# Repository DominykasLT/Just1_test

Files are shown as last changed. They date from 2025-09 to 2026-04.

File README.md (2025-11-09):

# Just1 - An Open-Source Autonomous Mecanum Wheel Robot

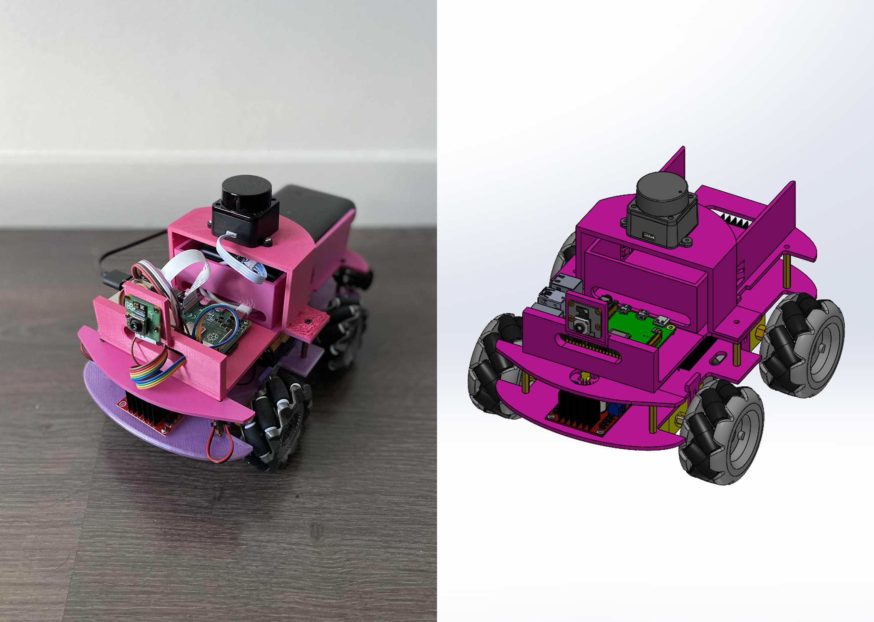
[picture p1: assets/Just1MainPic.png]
Just1MainPic


# Watch the Demo!
<a href="https://www.youtube.com/watch?v=m_tZ3eg-KsA" target="_blank">
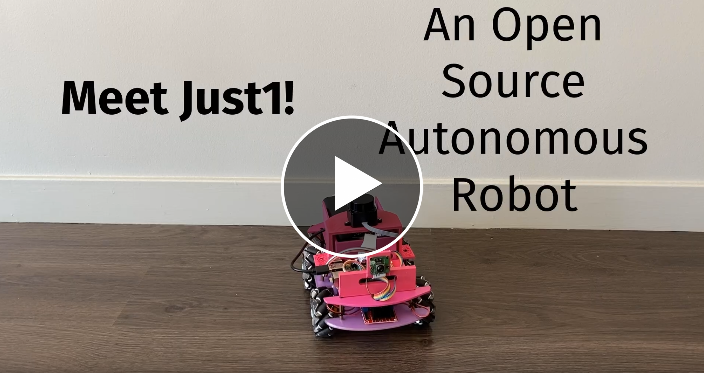
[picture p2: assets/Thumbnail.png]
Watch the demo
  
</a>

<br>
<br> 

I have written 2 blog articles about Just1:   
- [How I built a small autonomous robot](https://nrdrgz.github.io/2025/10/21/building-just1-autonomous-robot/)
- [How I used Foxglove](https://nrdrgz.github.io/2025/10/22/foxglove-studio-robotics-visualization/)

Just1 is an open-source robotics platform designed for learning and experimentation.  
It can navigate manually or autonomously, follow a path, avoid obstacles.  

Its hardware stack is composed of:

- Raspberry Pi 4
- Mecanum wheels
- TT motors
- 2D Lidar
- Rasberry Pi Camera
- IMU

Its software stack is composed of:

- ROS2 Jazzy for middleware
- Madgwick filter for IMU
- RTAB-Map for SLAM and odometry
- Nav2 for navigation
- Foxglove for sensor feedback and overall monitoring

Complete build cost: just $250.

Just1 operates in two modes: autonomous navigation with Lidar-based obstacle avoidance, or manual control via gamepad.  
Originally designed for camera-only VSLAM navigation, Just1 now uses Lidar for more reliable obstacle detection and easier software development. Future versions will integrate both camera and Lidar for enhanced autonomous navigation.  
One limit of the current architecture is that obstacles below 20cm are not detected due to the Lidar's position.

Here are some performance highlights (tested on a flat indoor surface):
- Maximum forward speed: 0.6 m/s
- Maximum sideways (lateral) speed: 0.5 m/s
- Maximum rotational speed: 3.5 rad/s (204°/s)
- Operates reliably in complete darkness thanks to its Lidar

## Project Goals

Just1 was created with these objectives in mind:
- Create an affordable, well-documented platform for robotics learning and experimentation
- Develop practical robotics skills, both in hardware and software
- Share knowledge and encourage others to build their own robots

## Workspace Organization

### Hardware
Located in `/Bot/Hardware`:
- Bill of Materials (BoM)
- CAD design files
- Wiring diagrams

### Software
Located in `/Bot/Software`:
- ROS2 packages
- Installation guides
- Manual and autonomous control documentation

## Current Features

- Complete hardware design with BoM and CAD files
- Comprehensive software documentation for Raspberry Pi setup and ROS2 installation
- Manual control using Nintendo controller
- Autonomous navigation using SLAM and Nav2
- Sensor feedback accessible via Foxglove

## Long-term Goals and Potential Improvements

- Add a Docker image for easier and faster deployment
- Replace AA batteries with voltage booster for simplified power management
- Add a bunch of unit tests 
- Add support for carrying the SO-101 robotic arm
- Add wheel encoders to improve ICP odometry
- Add an explorer node to automatically explorer and discover the frontiers of the map
- Use camera in combination with the Lidar for autonomous navigation and obstacle avoidance
- Create a simulation environment in NVIDIA Isaac Sim with Just1 replica for training navigation algorithms before hardware deployment
- Integrate memory/latency profilers to optimize processes and detect memory leaks
- Perform navigation through end-to-end neural network architecture instead of VSLAM

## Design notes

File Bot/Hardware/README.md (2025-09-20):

# Just1 Hardware

This folder contains hardware documentation and files for the Just1 robot.

## Bill of Materials
See `Bill_of_material.md` for complete parts list and pricing. Total cost is around $250.

**Key Components:**
- Raspberry Pi 4 (8GB) - Control unit
- 4x Mecanum wheels with TT motors - Omnidirectional movement
- 2x L298N motor drivers - Motor control
- LD19 Lidar - 2D scanning for navigation
- MPU6050 IMU - Orientation sensing
- Camera Module 3 - Optional vision sensor
- Power bank (5V 3A) - Pi power supply
- 6x AA battery holder - Motor power (9V)
The 6x AA battery holder can eventually be replaced with a rechargeable battery pack or by connecting the motors directly to the power bank using an appropriate power adapter.

**Additional parts:** Jumper wires, screws, hex pylons, on/off switch, and basic tools.

## 3D Models
- **Assembly**: `CAD/Just1Assembly.STEP` - Complete robot model
- **Print Files**: `CAD/ToPrint/` - STL files for 3D printing the different parts.

## Wiring Schematics
- `WiringMotorDrivers.png` - Motor driver connections
- `WiringPower.png` - Power distribution diagram

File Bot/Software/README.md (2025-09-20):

# Just1 Software

Instructions to set up the robot from a raw SD card to autonomous navigation.

## Installation

1. **Install Ubuntu Server 24.04 on your Pi**
   - See `How_to/How_to_Install_Ubuntu_on_Pi.md`
   - Connect via SSH to your Pi, then continue

2. **Install ROS2 on your Pi**
   - See `How_to/How_to_Install_ROS2_on_Pi.md`
   - Note: Do not use a virtual environment (causes issues with Camera and ROS2)

3. **Install git and clone this repository on your Pi**
```bash
sudo apt install git -y
git clone https://github.com/NRdrgz/Just1.git
cd Just1/Bot/Software
```

4. **Install Dependencies**
```bash
sudo apt install python3-pip python3-gpiozero python3-pygame libcap-dev ninja-build libyaml-dev python3-yaml python3-ply python3-jinja2 meson ros-jazzy-foxglove-bridge ros-jazzy-foxglove-msgs python3-smbus i2c-tools ros-jazzy-rtabmap-ros ros-jazzy-imu-filter-madgwick ros-jazzy-navigation2 ros-jazzy-nav2-bringup
sudo pip install --break-system-packages -r requirements.txt
```

5. **Build libcamera from source**
   - libcamera is not available on Ubuntu Server 24.04 (as of July 2025)
```bash
cd ~
git clone https://git.libcamera.org/libcamera/libcamera.git
cd libcamera
meson setup build
sudo ninja -C build install
```
   Add directory to Python search path:
```bash
echo 'export PYTHONPATH=/usr/local/lib/python3/dist-packages:$PYTHONPATH' >> ~/.bashrc
source ~/.bashrc
```

And libcamera-apps
```bash
cd ~
git clone https://github.com/raspberrypi/libcamera-apps.git
cd libcamera-apps
meson setup build
sudo ninja -C build install
```
   Add directory to Python search path:
```bash
echo 'export PYTHONPATH=/usr/local/lib/aarch64-linux-gnu/dist-packages:$PYTHONPATH' >> ~/.bashrc
source ~/.bashrc
echo "/usr/local/lib/aarch64-linux-gnu" | sudo tee /etc/ld.so.conf.d/libcamera.conf
sudo ldconfig
```

6. **Connect Nintendo Pro Controller (optional)**
   - See `How_to/How_to_Connect_Nintendo_Pro_Controller.md`

7. **Build ROS2 packages**
```bash
cd ~/Just1/Bot/Software
colcon build --symlink-install
```

When working on developing the robot, to build a single package you can do <br>
```bash
colcon build --packages-select <package_name> --symlink-install
```

8. **Source workspace**
```bash
source install/setup.bash
```

## Manual Control

At this point, you can control the robot manually.  
To start the manual control system:

```bash
ros2 launch just1_bringup just1.launch.py mode:=manual
```

If you have connected your controller earlier, you should be able to control the robot manually.

## Autonomous Control

Start autonomous navigation:

```bash
ros2 launch just1_bringup just1.launch.py mode:=autonomous
```

You'll need to use Foxglove to visualize the map and provide a goal to the robot.

## Using Foxglove

The `foxglove_bridge_node` used in `just1_bringup` selects the relevant topics to whitelist for Foxglove.

There are many tutorials available online on how to use Foxglove. It is a powerful tool that allows you to visualize logs, send messages on topics, use ROS2 services, and more.  
We'll focus here on the minimum setup needed to have camera feedback, a map of the surroundings, and the ability to give goals to the robot.

### Setup

1. **Download Foxglove** from https://foxglove.dev/
2. **Open a new connection** > WebSocket connection > Input `ws://raspberrypi:8765` (if you followed `Reads/How_to_Install_Ubuntu_on_Pi.md` and set the hostname as `raspberrypi.local`)
3. **Add panels** to visualize your data

### Required Panels

#### Image Panel
- Add an **Image Panel**
- In the panel settings, select the `/camera/video_h264` topic

#### 3D Map Panel
- Add a **3D Map Panel**
- In the panel settings, configure:
  - **Frame** > Display Frame > `map`
  - **Transform** > Hide all except `base_link` or `odom`
  - **Topics** > Visualize all except `/camera/video_h264`
  - **Publish** > 2D pose topic should be `/goal_pose`

### Navigation
- In the top right corner of the map, right-click on the icon below the ruler > **Publish 2D pose**
- Click on the map to set a goal
- The robot should navigate autonomously to the point while avoiding obstacles!

## Performance Notes

Here is a screenshot of `htop` running while the robot is navigating autonomously:

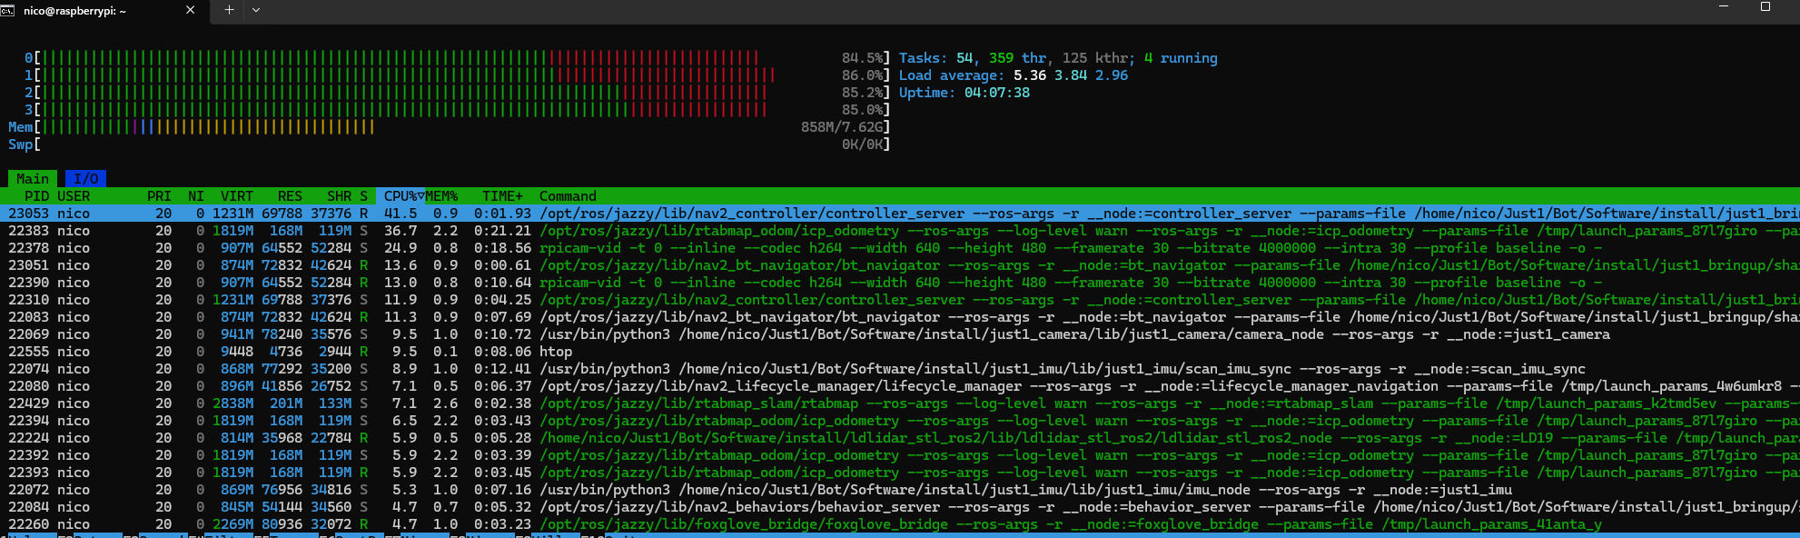
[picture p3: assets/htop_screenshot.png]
htop_screenshot


We can see that CPU usage is near 100%, with Nav2 and RTAB-Map at the top.  
The camera node consumes a significant amount of CPU resources. Moving from JPEG to H.264 encoding definitely improved performance, but it can probably be optimized further by implementing it in C++.
The camera node can eventually be deactivated as it is not strictly required for navigation.

```
 ______  __  __  ______  __  __  __  __      __    __  _____   __  __     
/\__  _\/\ \/\ \/\  _  \/\ \/\ \/\ \/\ \    /\ \  /\ \/\  __`\/\ \/\ \    
\/_/\ \/\ \ \_\ \ \ \L\ \ \ `\\ \ \ \/'/'   \ `\`\\/'/\ \ \/\ \ \ \ \ \   
   \ \ \ \ \  _  \ \  __ \ \ , ` \ \ , <     `\ `\ /'  \ \ \ \ \ \ \ \ \  
    \ \ \ \ \ \ \ \ \ \/\ \ \ \`\ \ \ \\`\     `\ \ \   \ \ \_\ \ \ \_\ \ 
     \ \_\ \ \_\ \_\ \_\ \_\ \_\ \_\ \_\ \_\     \ \_\   \ \_____\ \_____\
      \/_/  \/_/\/_/\/_/\/_/\/_/\/_/\/_/\/_/      \/_/    \/_____/\/_____/     
```

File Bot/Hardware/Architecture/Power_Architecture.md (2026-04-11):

# Power Architecture

## Overview

Just1 uses a single 4S Graphene LiPo drone battery (14.8V nominal, 16.8V max, 1300mAh, 75C) as the sole power source for the entire robot. A single battery eliminates the need for a separate Pi power bank and a motor pack. The LiPo is extremely lightweight, heavily improving the robot's agility and TT motor performance. A BX100 buzzer MUST be plugged into the balance port during operation for low-voltage warning.

## Power Distribution Diagram

```
┌─────────────────────────────────────────────────────────────┐
│  4S Graphene LiPo Battery (14.8V nominal, 16.8V max)       │
│  Requires external BX100 buzzer for low-voltage alarm!      │
└──────────────────┬──────────────────────────────────────────┘
                   │ XT60 (red + / black −) → master switch (see Step 1) → XT60 out → 1→2 splitter → loads
                   │
      ┌────────────┴────────────┐
      │                         │
      ▼                         ▼
┌───────────────┐     ┌──────────────────────────────────┐
│ DC-DC Buck    │     │  DC-DC Buck Converter            │
│ Converter     │     │  Input: up to 16.8V              │
│ (XL4016)      │     │  Output: 5V / 8A (40W)           │
│ Out: 6.0V/8A  │     │  (XL4016)                        │
└──────┬────────┘     └─────────────┬────────────────────┘
       │                            │ BuckVout (5V rail)
       │               ┌────────────┴──────────────────────────────┐
       ▼               │                                           │
┌───────────────┐      ▼                    ▼                      │
│  2× TB6612FNG │ ┌──────────────┐   ┌─────────────────┐           │
│  Motor Driver │ │ RelayCoil+   │   │ Esp32VIN        │           │
│               │ │ Pi5V path    │   │ (always on 5V)  │           │
│  VM: 6.0V     │ │ (switched)   │   └────────┬────────┘           │
│  (safe limits)│ └──────┬───────┘            │                    │
│               │        │    ESP32 GPIO      │                    │
│  4× Encoder   │        │    closes relay    │                    │
│  TT Motors    │        ▼                    │                    │
└───────────────┘ ┌──────────────┐◄───────────┘                    │
                  │ Pi5V_USB-C   │                                 │
                  │ via relay NO │                                 │
                  └──────────────┘                                 │
```

**5V topology:** **ESP32 VIN** and **relay module VCC** tie directly to **buck VOUT+**. Only the **Raspberry Pi 5V** path runs **through the relay contacts** (Pi off, ESP32 still powered). “Upstream of the relay” means **parallel to the Pi feed**, not “before the battery master switch.”

### How the Battery Connects to the System — Physical Wiring Guide

Your battery has two wires: **+ (red)** and **− (black)**. Here is exactly where each wire goes, step by step.

#### Step 1: Battery → XT60 → master switch → XT60 (your harness)

An **XT60** is always **two conductors**: **red = battery +**, **black = battery −** (same pin names on male and female).

Many RC-style harnesses use a **DPST** toggle: **both red and black** run through the switch. **OFF** disconnects the whole pack; **ON** connects both. That matches a battery XT60 on one side of the switch and a second XT60 on the load side — both polarities are switched together.

(Some builds switch **only** the red wire and leave black always tied to a ground bus. Your photos use **both** switched; that is fine and is often safer for storage.)

```
Battery ──XT60──► [ DPST: RED + BLACK both through switch ] ──XT60──► rest of robot
```

#### Step 2: After the switch — 1→2 Splitter → 5V Buck + 6V Buck

Plug the **load-side XT60** of the switch into a **1-to-2 parallel XT60 splitter** (or cut/splice thick wires directly). The two output pairs route the raw up to 16.8V battery voltage to your two buck converters:

| Branch | Red → | Black → |
| --- | --- | --- |
| 1 | Logic Buck (XL4016) **VIN+** | Logic Buck **VIN−** |
| 2 | Motor Buck (XL4016) **VIN+** | Motor Buck **VIN−** |

*Note: The Motor Buck's output (set to exactly 6V) then splices to feed the `VM` pins of both TB6612FNG drivers so they receive a safe 6V limit. Do not connect the battery directly to the TB6612FNG `VM` pins or they will explode (15V limit).*

**Yes — every branch needs both red and black.** DC only flows in a loop; **VM/VIN+ without GND/VIN−** (or the reverse) does nothing useful and can damage something if signals are connected without a common return.

The three blacks from the splitter are **electrically the same node** (battery negative after the switch). They still need to meet the **rest** of the system ground (ESP32, Pi, PCA9685, buck **VOUT−**, etc.) at one **common ground** so logic signals share a reference — use a ground bus, star point, or the splitter blacks as part of that bus.

#### Step 3: COMMON GND BUS — every device connects its ground here

The **three blacks** from the splitter (to TB6612 ×2 and XL4016 **VIN−**) are already on battery **−** (via the switch, if DPST). Tie those points together with **all other grounds** below (same metal/node):

From the common ground bus, run **black wires** to every device's GND:

| Wire | From | To | Terminal Name |
|---|---|----|---|
| Black wire 1 | GND bus | TB6612FNG chip #1 | **GND** |
| Black wire 2 | GND bus | TB6612FNG chip #2 | **GND** |
| Black wire 3 | GND bus | XL4016 Buck Converter | **VIN−** (or **IN−**) |
| Black wire 4 | GND bus | ESP32 DevKit | **GND** pin |
| Black wire 5 | GND bus | Relay module | **GND** |
| Black wire 6 | GND bus | Raspberry Pi 5 | **GND** pin (or USB-C ground) |
| Black wire 7 | GND bus | PCA9685 | **GND** |

> **Why is the shared ground critical?** Every signal wire (I2C, UART, GPIO, PWM) is measured as a voltage *relative to ground*. If two devices don't share the same ground, a "HIGH" signal from one device could look like noise to another. Worse, current can flow through data lines trying to find a ground path — this can damage GPIO pins.

#### Step 4: 5V rail from the Buck Converter

The XL4016 buck converter has output terminals: **VOUT+** and **VOUT−**. Set the output to **5.0V** using the adjustment potentiometer (measure with a multimeter before connecting anything!). 

From the buck converter's **VOUT+** (5V), run red wires to:

| Wire | From | To | Terminal Name | Notes |
|---|---|----|---|---|
| Red wire 4 | VOUT+ | ESP32 DevKit | **VIN** pin | ESP32's onboard regulator converts 5V → 3.3V |
| Red wire 5 | VOUT+ | Relay module | **VCC** | Powers the relay coil |
| Red wire 6 | VOUT+ → through relay → | Pi 5 | **USB-C 5V** (or GPIO 5V) | Only powered when ESP32 closes the relay. Use 18AWG wire to minimise contact-resistance voltage drop (mechanical relay contacts can drop ~0.2–0.3V under 5A load). |
| Red wire 7 | VOUT+ | PCA9685 | **V+** only | Servo motor power rail (up to 1.4A stall for 2× SG90) |
| Red wire 8 | ESP32 3.3V out | PCA9685 | **VCC** | Logic power — MUST be 3.3V, NOT 5V. The PCA9685 has 10 kΩ I2C pull-ups tied to VCC; if VCC = 5V, SDA/SCL are pulled to 5V and will over-voltage the ESP32 GPIO (3.3V max), causing long-term damage. |

The buck converter's **VOUT−** connects to the same **common ground bus**.

#### Complete Physical Wiring Diagram

```
                                                    │
                                              VOUT+ (5V) ──► ESP32 / relay / PCA9685 / Pi (via relay)

(−) BLACK ─XT60─► both legs ON/OFF ──XT60──►  ├── black → TB6612 #1 GND
             (same switch)                   ├── black → TB6612 #2 GND
                                             └── black → XL4016 VIN−
                                                    │
                              COMMON GND ◄──── VOUT− + ESP32 GND + Pi GND + relay GND + PCA9685 GND
```

> **Summary:** After the switch you have one **XT60 pair** (red + black). The **1→2 splitter** routes battery power to two buck converters. The 5V logic buck powers the compute string. The 6V motor buck feeds purely the VM pins of the dual TB6612FNG drivers. All blacks meet at a **common ground**.

## Rail Summary

| Rail | Voltage | Source | Powers |
| --- | --- | --- | --- |
| Main bus | 14.8V (16.8V max) | 4S Graphene LiPo | 5V Logic Buck input, 6V Motor Buck input |
| Motor rail | 6.0V | 6V Motor Buck → TB6612FNG **VM** | 4× TT encoder motors (Full 0-100% PWM safe) |
| 5V logic rail | 5V / up to 8A | High-current DC-DC Buck (XL4016) | ESP32 VIN (via onboard LDO), Relay coil VCC, Pi 5 (via relay), PCA9685 **V+** (servo motor power only) |
| 3.3V | 3.3V | ESP32 onboard AMS1117 LDO (from 5V VIN) | ESP32 logic, PCA9685 **VCC** (I2C logic power — avoids 5V pull-ups on ESP32 I2C bus), pan/tilt servo signal lines |

## Key Design Decisions

**Why 4S Graphene LiPo?**
At ~150g, a drone battery is massively lighter than standard Li-Ion or LiFePO4 robot packs. TT motors and mecanum wheels perform notoriously poorly under heavy payloads; dropping 600g out of the chassis yields a much faster, agile robot that can slide longitudinally without stalling. 

**Why power motors from a dedicated 6V buck?**
Because the drone battery reaches 16.8V fully charged, it exceeds the TB6612FNG motor driver's absolute maximum rating of 15V. Pumping 16.8V directly into the motor drivers will fry them. By using a second high-current XL4016 buck converter (8A) to cap the motor supply (VM) at exactly 6.0V, we protect the driver chip *and* allow the Python code to safely output a full 100% PWM duty cycle curve to the TT motors (which are rated for 6V). We strictly use an 8A XL4016 rather than a 3A LM2596 because 4 motors can generate a combined 5.6A+ load during simultaneous stalls; an LM2596 would collapse or overheat during the stall window.

Optional **INA219/INA226** (I2C) high-side or low-side shunt sensing on the motor path (see BOM) can back up encoder-based stall cutout if an encoder cable fails.

**Buck Converter and Servo Safety:**
The Pi 5 alone can draw up to 5A. Therefore, a high-current buck converter like the XL4016 (rated up to 8A) is strictly required — do not use an LM2596(HV) as it will overheat. The pan/tilt SG90 servos are powered through a PCA9685 servo driver: the PCA9685 has a dedicated **V+** servo power pin connected to the 5V rail (for motor current), and a separate **VCC** logic pin connected to the **ESP32 3.3V** output. This is critical: the PCA9685 has 10 kΩ I2C pull-up resistors tied to VCC. If VCC were 5V, the SDA/SCL lines would be pulled to 5V, over-voltaging the ESP32's 3.3V-tolerant I2C GPIO pins and causing hardware damage over time. At 3.3V VCC, the PCA9685 logic still functions correctly and the I2C bus stays safely within the ESP32's input voltage range.

**ESP32 standby behavior and Power Switching:**
The ESP32 **VIN** is fed from **buck VOUT+** on the **same** 5V bus as the relay coil — **not** through the relay’s switched path to the Pi — so the ESP32 stays alive when the Pi is off. (Do not confuse this with the **battery master** DPST switch, which removes all loads.) The ESP32 draws ~10μA in deep-sleep. On wake (BLE, RTC, or button), it drives the relay so **only** the Pi 5V feed is energized. **Crucial Note:** A high-side switch or relay on the **Pi 5V path** preserves a **shared system ground**. A low-side N-channel cut on Pi “ground” would break that reference and risks current through data lines.

**LiPo Protection (No BMS!):**
Drone LiPos **DO NOT** have an internal BMS. If you leave the robot on, it will drain the battery to 0V and cause a chemical fire hazard upon recharging. You must plug a BX100 low-voltage buzzer into the white balance port on the battery to screech at you when any cell hits 3.5V so you can immediately power off the robot.

---

## Battery Specifications

| Property | Value |
| --- | --- |
| Chemistry | Graphene LiPo |
| Configuration | 4S (4 cell series) |
| Nominal voltage | 14.8V |
| Full charge voltage | 16.8V |
| Absolute minimum limit | ~12.8V (3.2V/cell) |
| Capacity | 1300mAh (19.2Wh) |
| Discharge rating | 75C |
| Weight | ~150g |

> **Charger:** Use a standard RC **LiPo balance charger**. Ensure the mode is set to **LiPo (4.2V/cell)**, not LiFePO4!

---

## Power Budget Estimate

| Consumer | Voltage | Peak Current | Average Power |
| --- | --- | --- | --- |
| Raspberry Pi 5 (under load) | 5V | 5.0A | ~15.0W |
| 2× SG90 servos | 5V | 1.4A | ~2.0W |
| ESP32 + Aux (active) | 5V / 3.3V | 0.3A | ~1.5W |
| 4× TT motors (running loaded) | 6V | ~2.0A | ~12.0W |
| **System total** | — | — | **~30.5W** |

With an average draw of ~30W, the 19.2Wh drone battery will yield a runtime of **~35-45 minutes**. Keep the low voltage alarm loud!

The XL4016 buck converter is rated 8A — the 5V rail peak of ~6.7A is within spec with 1.3A headroom. ✅

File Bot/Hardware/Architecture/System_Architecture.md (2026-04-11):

# System Architecture

## Hardware Block Diagram

```
                         ┌─────────────────────────────────────────────────────────────┐
                         │                    RASPBERRY PI 5 (8GB)                     │
                         │                                                              │
                         │  ┌──────────────┐  ┌───────────┐  ┌──────────────────────┐ │
                         │  │  ROS2 Stack  │  │  Nav2     │  │  just1_camera node   │ │
                         │  │  (Ubuntu)    │  │  (SLAM /  │  │  (AI inference via   │ │
                         │  │             │  │  Autonomy)│  │  IMX500 CSI stream)  │ │
                         │  └──────┬───────┘  └─────┬─────┘  └──────────┬───────────┘ │
                         │         │                 │                    │              │
                         │  ┌──────▼─────────────────▼────────────────── ▼───────────┐ │
                         │  │                  GPIO / Serial / I2C / CSI Bus          │ │
                         │  └──┬──────┬─────────┬────────┬────────┬──────────────────┘ │
                         └─────│──────│─────────│────────│────────│────────────────────┘
                               │      │         │        │        │
              ┌────────────────┘      │         │        │        └──────────────────┐
              │                       │         │        │                           │
              ▼                       ▼         ▼        ▼                           ▼
  ┌───────────────────┐   ┌──────────────┐  ┌──────┐  ┌─────────────────┐  ┌────────────────┐
  │  2× TB6612FNG     │   │  LD19 Lidar  │  │IMU   │  │ ESP32 DevKit    │  │ AI Camera      │
  │  Motor Drivers    │   │  (UART/USB)  │  │MPU   │  │                 │  │ (CSI-2, IMX500)│
  │                   │   │              │  │6050  │  │ • Wake-up ctrl  │  │                │
  │  AIN1/2, BIN1/2,  │   │  360° scan   │  │(I2C) │  │ • I2C→ PCA9685  │  │ On-sensor      │
  │  PWMA/B per chip  │   │  10m range   │  │      │  │ • Encoder read  │  │ object detect  │
  │  STBY shared      │   │  12Hz scan   │  │      │  │                 │  │                │
  └────────┬──────────┘   └──────────────┘  └──────┘  └────────┬────────┘  └───────┬────────┘
           │                                                     │ I2C               │
  ┌────────▼──────────┐                                 ┌────────▼────────┐  ┌───────▼────────┐
  │  4× TT Encoder    │                                 │  PCA9685        │  │  Camera angle  │
  │  Motors           │                                 │  Servo Driver   │  │  follows target│
  │                   │                                 │  (I2C, 0x40)    │  │                │
  │  Motor+, Motor-   │                                 │  V+: 5V rail    │  │                │
  │  ENC_A, ENC_B     │                                 │  Ch0: Pan SG90  │  │                │
  │  per motor (×4)   │                                 │  Ch1: Tilt SG90 │  │                │
  └────────┬──────────┘                                 └────────┬────────┘  └────────────────┘
           │                                                      │
  ┌────────▼──────────┐                                 ┌────────▼────────┐
  │ 60mm Mecanum      │                                 │  Pan/Tilt       │
  │ Wheels (×4)       │                                 │  Servo Mount    │
  │                   │                                 │  (SG90 × 2)    │
  │ Omnidirectional   │                                 │                 │
  │ drive (strafe,    │                                 │  Pan: ±90°      │
  │ rotate in place,  │                                 │  Tilt: ±45°     │
  │ diagonal)         │                                 └─────────────────┘
  └───────────────────┘
```

---

## Component Connections

### Raspberry Pi 5 ↔ TB6612FNG (Motor Control)

Each TB6612FNG controls 2 motors. 2 chips → 4 motors total.

| Signal | Pi GPIO | TB6612FNG #1 | TB6612FNG #2 |
| --- | --- | --- | --- |
| Motor FL AIN1 | GPIO 17 | AIN1 | — |
| Motor FL AIN2 | GPIO 22 | AIN2 | — |
| Motor FL PWM | GPIO 18 (hw PWM1_0) | PWMA | — |
| Motor FR BIN1 | GPIO 23 | BIN1 | — |
| Motor FR BIN2 | GPIO 24 | BIN2 | — |
| Motor FR PWM | GPIO 13 (hw PWM0_1) | PWMB | — |
| Chip #1 Standby | GPIO 25 | STBY | — |
| Motor RL AIN1 | GPIO 27 | — | AIN1 |
| Motor RL AIN2 | GPIO 10 | — | AIN2 |
| Motor RL PWM | GPIO 12 (hw PWM0_0) | — | PWMA |
| Motor RR BIN1 | GPIO 9 | — | BIN1 |
| Motor RR BIN2 | GPIO 11 | — | BIN2 |
| Motor RR PWM | GPIO 19 (hw PWM1_1) | — | PWMB |
| Chip #2 Standby | GPIO 8 | — | STBY |
| Logic supply (VCC) | Pi 3.3V pin | VCC | VCC |
| Motor supply (VM) | Output of 6.0V Motor Buck | VM | VM |
| Ground | GND | GND | GND |

> Pi 5 has exactly 4 hardware PWM channels (GPIO 12, 13, 18, 19) — all 4 are used for motor speed control.
> STBY: pulled HIGH by `setup()` in `utils_motors.py`, pulled LOW by `cleanup()` to enter low-power standby.
> These pin assignments are implemented in `just1_motors/utils_motors.py`.

---

### Raspberry Pi 5 ↔ Encoder Signals (via 74LVC125A Level Shifter)

Each TT encoder motor has 2 quadrature encoder output signals (ENC_A, ENC_B). These signals must be level-shifted from 5V (encoder VCC) to 3.3V (Pi 5 GPIO max) before reaching the Pi.

**Level shifter wiring (74LVC125A):**

```
Encoder motor                74LVC125A               Pi 5 GPIO
(5V signal out) ──► A pin ──► Y pin (3.3V out) ──► GPIO input pin
                    OE pin pulled to GND (always enabled)
                    VCC = 3.3V (from Pi 3.3V rail)
                    GND = common ground
```

Two 74LVC125A chips needed: each has 4 channels, 4 motors × 2 signals = 8 total.

| Motor | ENC_A (Pi GPIO) | ENC_B (Pi GPIO) |
| --- | --- | --- |
| Front-Left | GPIO 4 | GPIO 5 |
| Front-Right | GPIO 6 | GPIO 7 |
| Rear-Left | GPIO 16 | GPIO 20 |
| Rear-Right | GPIO 21 | GPIO 26 |

> The LVC variant of the 125 buffer is specifically designed to be overvoltage-tolerant, meaning it can safely accept 5V inputs while powered from 3.3V to step the signals down. Do not use AHCT or HC variants for step-down.

---

### Raspberry Pi 5 ↔ LD19 Lidar (SLAM / Obstacle Avoidance)

| Connection | Detail |
| --- | --- |
| Interface | USB (via USB-to-serial adapter, included with LD19) |
| Pi port | Any USB-A on Pi 5 |
| ROS2 package | `ldlidar_stl_ros2` (already in repo) |
| Topic published | `/scan` (sensor_msgs/LaserScan) |
| Scan rate | 10–12 Hz |
| Range | 0.02–12m |

---

### Raspberry Pi 5 ↔ MPU6050 IMU

| Signal | Pi GPIO | MPU6050 |
| --- | --- | --- |
| I2C SDA | GPIO 2 (SDA1) | SDA |
| I2C SCL | GPIO 3 (SCL1) | SCL |
| Power | Pi 3.3V | VCC |
| Ground | GND | GND |
| I2C address | 0x68 (AD0 low) | — |

---

### Raspberry Pi 5 ↔ AI Camera (Sony IMX500)

| Connection | Detail |
| --- | --- |
| Interface | CSI-2 (camera ribbon cable) |
| Pi port | CAM0 or CAM1 connector on Pi 5 |
| Driver | `libcamera` + Raspberry Pi camera stack |
| IMX500 inference | Runs directly on sensor chip, result streamed via CSI |
| Resolution | Up to 12MP (AI inference typically runs at lower resolution crop) |
| ROS2 node | `just1_camera` — subscribes to libcamera, publishes `/camera/image_raw` |

---

### ESP32 DevKit ↔ Raspberry Pi 5 (Wake + Coordination)

| Signal | ESP32 Pin | Destination | Purpose |
| --- | --- | --- | --- |
| Relay Control | GPIO 32 | High-Side Relay coil control | HIGH = Pi powered ON, LOW = Pi powered OFF |
| UART TX | GPIO 17 (U2TXD) | Pi GPIO 15 (RXD) | Send encoder ticks / status to Pi (optional) |
| UART RX | GPIO 16 (U2RXD) | Pi GPIO 14 (TXD) | Receive pan/tilt commands from Pi (optional) |
| I2C SDA | GPIO 21 | PCA9685 SDA | I2C servo driver — pan/tilt PWM commands |
| I2C SCL | GPIO 22 | PCA9685 SCL | I2C servo driver clock |
| Wake button | GPIO 33 | Physical button → GND | Wakes ESP32 from deep-sleep |
| Power | 5V rail (via LDO) | — | ESP32 3.3V internal reg |

**Wake-up sequence:**
1. ESP32 enters deep-sleep → draws ~10μA. (Its UART TX pin is configured as a high-impedance input before sleep to prevent back-powering the Pi.)
2. Wake trigger fires (BLE packet, button press, or RTC timer)
3. ESP32 pulls relay control pin HIGH
4. Pi 5V rail energizes → Pi boots. (ESP32 keeps UART TX as a high-impedance input during this phase to avoid pushing 3.3V into the unpowered Pi RX pin.)
5. Pi completes boot and signals ESP32 over UART that it is ready
6. ESP32 configures its UART TX pin as an output and begins sending servo commands to PCA9685 over I2C and forwarding data to Pi over UART.

**Shutdown sequence:**
1. Pi sends UART shutdown signal to ESP32
2. Pi runs `sudo shutdown -h now`
3. After Pi GPIO goes low (confirms shutdown), ESP32 immediately reconfigures its UART TX pin as a high-impedance input to prevent back-powering.
4. ESP32 pulls relay control pin LOW
5. ESP32 enters deep-sleep

---

### ESP32 ↔ PCA9685 (I2C Servo Driver)

| Signal | ESP32 Pin | PCA9685 Pin | Notes |
| --- | --- | --- | --- |
| I2C SDA | GPIO 21 | SDA | I2C data — default ESP32 I2C bus |
| I2C SCL | GPIO 22 | SCL | I2C clock |
| Logic power | **3.3V** output | **VCC** | **Must be 3.3V from ESP32**, not 5V. The PCA9685 has 10 kΩ I2C pull-up resistors tied to VCC; if VCC = 5V, SDA/SCL are pulled to 5V and will over-voltage the ESP32 GPIO inputs (3.3V max), causing hardware damage. |
| Servo power | 5V rail (buck) | V+ | Dedicated servo motor power rail on PCA9685, isolated from VCC logic. Sources up to 1.4A stall for 2× SG90. |
| Ground | GND | GND | Common ground |

> PCA9685 default I2C address: **0x40** (all address pins low). Up to 62 boards can be chained on one I2C bus.
> **VCC** (logic) is wired to **ESP32 3.3V**; **V+** (servo motor power) is wired to the **5V buck rail**. The PCA9685 internally isolates V+ from VCC so SG90 stall current spikes do not propagate to the logic rail or Pi. Keeping VCC at 3.3V ensures I2C pull-ups hold SDA/SCL at a safe level for the ESP32.

### PCA9685 ↔ Pan/Tilt Servo Mount

| Channel | Component | Signal spec |
| --- | --- | --- |
| Ch 0 | Pan servo (SG90) | 50Hz PWM — 1ms = −90°, 1.5ms = 0°, 2ms = +90° |
| Ch 1 | Tilt servo (SG90) | 50Hz PWM — same spec; mechanically limited to ±45° in firmware to protect CSI ribbon |

| Power | Source | Notes |
| --- | --- | --- |
| Servo VCC (V+) | PCA9685 V+ → 5V rail | SG90 rated 4.8–6V; 5V rail is within spec |
| Servo GND | GND | Common ground through PCA9685 |

> SG90 draws up to 700mA stall per servo. Power is sourced through the PCA9685 V+ pin, not from ESP32 GPIO or VCC — ESP32 3.3V output pin is rated 50mA and cannot source servo current.

---

## Software / ROS2 Node Map

```
[Joystick Controller]──────►[just1_joystick_driver]──────►/joy  (manual)
                                                             │
[LD19 Lidar]───────────────►[ldlidar_stl_ros2]────────────►/scan
         │                                                   │
         └────────────►[sync + icp_odometry (rtabmap_odom)]──►/odom ──►[Nav2 Stack]
                              ▲                                │
[MPU6050 IMU]──►[just1_imu]───┘                                │
                                                              ▼
[AI Camera (IMX500)]────────►[just1_camera]──────────────►/camera/...   Autonomous nav
                                                             │          + SLAM mapping
[TB6612FNG + TT motors]────►[just1_motors]◄────────────────/cmd_vel
(encoders on Pi GPIO → `encoder_watcher` ENC_A edges → `feed_watchdog`; full quadrature /odom from wheels not implemented)
```

> Motor control: `just1_motors` (`manual_controller_node` / `autonomous_controller_node`) converts `/cmd_vel` (autonomous) or joystick input (manual) to per-wheel PWM and direction on the TB6612FNG. Encoder **ENC_A** lines (GPIO 4, 6, 16, 21) are read with **gpiozero + lgpio** (`encoder_watcher.py`) and call `feed_watchdog()` so the stall watchdog can detect blocked wheels. A **stall latch** blocks PWM after a trip until that wheel receives a zero command or an encoder edge clears the latch (prevents `/cmd_vel` streams from re-arming stall). **Odometry** for navigation remains **lidar + IMU** (`icp_odometry` in bringup), not wheel encoders.

---

## GPIO Pin Allocation Summary (Pi 5)

Motor control and STBY pin assignments match `just1_motors/utils_motors.py`. Encoder **ENC_A** pins are opened in `just1_motors/encoder_watcher.py` (same process as motor nodes). No conflicts between motor control, encoder, and communication pins.

| GPIO | Function | Connected To |
| --- | --- | --- |
| 2 | I2C SDA | MPU6050 SDA |
| 3 | I2C SCL | MPU6050 SCL |
| 4 | Encoder FL-A | 74LVC125A Y → Motor FL ENC_A |
| 5 | Encoder FL-B | 74LVC125A Y → Motor FL ENC_B |
| 6 | Encoder FR-A | 74LVC125A Y → Motor FR ENC_A |
| 7 | Encoder FR-B | 74LVC125A Y → Motor FR ENC_B |
| 8 | TB6612 #2 STBY | TB6612FNG #2 STBY |
| 9 | TB6612 #2 BIN1 | TB6612FNG #2 BIN1 (RR direction) |
| 10 | TB6612 #2 AIN2 | TB6612FNG #2 AIN2 (RL direction) |
| 11 | TB6612 #2 BIN2 | TB6612FNG #2 BIN2 (RR direction) |
| 12 | PWM0_0 (hw) | TB6612FNG #2 PWMA (RL speed) |
| 13 | PWM0_1 (hw) | TB6612FNG #1 PWMB (FR speed) |
| 14 | UART TXD | ESP32 RX (GPIO 16) |
| 15 | UART RXD | ESP32 TX (GPIO 17) |
| 16 | Encoder RL-A | 74LVC125A Y → Motor RL ENC_A |
| 17 | TB6612 #1 AIN1 | TB6612FNG #1 AIN1 (FL direction) |
| 18 | PWM1_0 (hw) | TB6612FNG #1 PWMA (FL speed) |
| 19 | PWM1_1 (hw) | TB6612FNG #2 PWMB (RR speed) |
| 20 | Encoder RL-B | 74LVC125A Y → Motor RL ENC_B |
| 21 | Encoder RR-A | 74LVC125A Y → Motor RR ENC_A |
| 22 | TB6612 #1 AIN2 | TB6612FNG #1 AIN2 (FL direction) |
| 23 | TB6612 #1 BIN1 | TB6612FNG #1 BIN1 (FR direction) |
| 24 | TB6612 #1 BIN2 | TB6612FNG #1 BIN2 (FR direction) |
| 25 | TB6612 #1 STBY | TB6612FNG #1 STBY |
| 26 | Encoder RR-B | 74LVC125A Y → Motor RR ENC_B |
| 27 | TB6612 #2 AIN1 | TB6612FNG #2 AIN1 (RL direction) |

> GPIO 8–11 are also the SPI0 pins. They are assigned to TB6612FNG #2 direction and standby here. SPI0 must remain disabled in `/boot/firmware/config.txt` (`dtparam=spi=off`) since the Lidar uses USB and no SPI device is connected.
> CSI camera uses the dedicated ribbon connector — not GPIO.
> Pan/tilt servo control is handled by the PCA9685 over **ESP32 I2C (GPIO 21 SDA / GPIO 22 SCL)** — not Pi GPIO. The Pi GPIO table above is complete as-is; no Pi pins are used for servo control.

---

## Issues and Resolutions

| Issue | Risk | Status | Resolution |
| --- | --- | --- | --- |
| Encoder signal voltage (5V vs 3.3V) | HIGH | ✅ RESOLVED | 74LVC125A quad level shifter added to BOM (2 chips, 8 channels total). LVC variant accepts 5V input while powered from 3.3V — safe for Pi 5 GPIO. |
| Motor voltage too high for TB6612 and TT motors (16.8V LiPo fully charged) | HIGH | ✅ RESOLVED | The 16.8V LiPo exceeds the 15V limit of the TB6612FNG. We added a dedicated 6.0V Buck Converter for the motor rail. Since the physical rail is 6V, the TB6612 is protected, and we can set `MAX_MOTOR_SPEED = 100` (full PWM range) in code safely. We specifically use an 8A XL4016 for this as smaller bucks (like the LM2596) will collapse under heavy TT motor stall spikes. |
| Pan/tilt cable management for CSI ribbon | MEDIUM | ✅ RESOLVED | 20cm flexible CSI extension cable added to BOM. Route cable along the tilt servo rotation axis to minimize flexion. Tilt range enforced at ±45° in ESP32 servo firmware to prevent over-twist. |
| Encoder reading accuracy under Linux RT | LOW-MEDIUM | ⚠️ NOTED | On Pi 5, prefer **gpiozero + lgpio** (same stack as motor PWM). `pigpio` is not suitable on Pi 5 (RP1 GPIO). For lowest jitter, route encoder signals to ESP32 and forward tick counts to Pi over UART (encoder ROS2 bridge). |
| Wheel encoder software on Pi | MEDIUM | ✅ RESOLVED (stall) | `encoder_watcher.py` feeds `feed_watchdog()` from ENC_A edges. Stall latch in `utils_motors.py` stops command streams from defeating the watchdog. Full quadrature odometry remains future work; navigation odometry stays lidar-based (`icp_odometry`). |
| ESP32 + Pi UART conflict during boot | LOW | ✅ RESOLVED | ESP32 UART moved to GPIO 16/17 (UART2) to avoid ESP32 ROM boot log spam on UART0. |
| Ground loop through MOSFET switch | HIGH | ✅ RESOLVED | Replaced IRF520 low-side switch with a High-Side Load Switch / Relay to maintain common system ground and prevent phantom powering the Pi via data lines. |
| Pi UART back-powering via ESP32 | HIGH | ✅ RESOLVED | If ESP32 is awake or sleeping with its UART TX driven HIGH, it will bleed 3.3V into the unpowered Pi's RX pin, powering the Pi via ESD diodes. This is mitigated by configuring the ESP32 UART TX pin as a high-impedance input prior to powering down the relay or prior to ESP32 deep sleep, and only initializing the UART TX as an output *after* the Pi boots. |
| Pi 5 power brownouts from servos | HIGH | ✅ RESOLVED | PCA9685 servo driver added. Its dedicated V+ power rail (isolated from the VCC logic pin) sources all SG90 stall current directly from the 5V bus without coupling transients back to the Pi logic supply. XL4016 8A buck converter provides headroom for Pi (5A) + both servos (700mA stall each) simultaneously. |
| TB6612FNG current limit (1.2A/ch) for TT motors | MEDIUM | ⚠️ MANAGED | DFRobot FIT0450 motors draw ~0.17A no-load, ~0.5A running, but 2.8A at stall — above TB6612FNG 1.2A continuous rating. Mitigated by hardware XL4016 8A motor buck handling the initial stall spike safely, while a software encoder-fed stall watchdog in `utils_motors.py` cuts PWM if a wheel does not produce ENC_A edges for ~500ms. |
| Drone LiPo lacks internal BMS protection | HIGH | ✅ MANAGED | A purely RC LiPo will drain to 0V and rapidly become a severe fire hazard. A BX100 RC Battery Alarm must be connected to the LiPo balance connector at all times during use. It screeches loudly if any cell drops to 3.5V, prompting manual shutdown. |
| SPI0 pins (GPIO 8–11) used for TB6612FNG #2 | LOW | ✅ ACCEPTABLE | No SPI device in this build. Disable SPI0 in device tree config. If SPI is needed in future, re-route TB6612FNG #2 direction pins to other free GPIO. |

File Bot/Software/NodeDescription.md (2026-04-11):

# Just1 ROS2 Node Description

This document provides a comprehensive description of each ROS2 node in the Just1 robot project, their roles, functionality, and communication patterns.

Here is a map of the main nodes and main topics taken from Foxglove while in autonomy.  
  
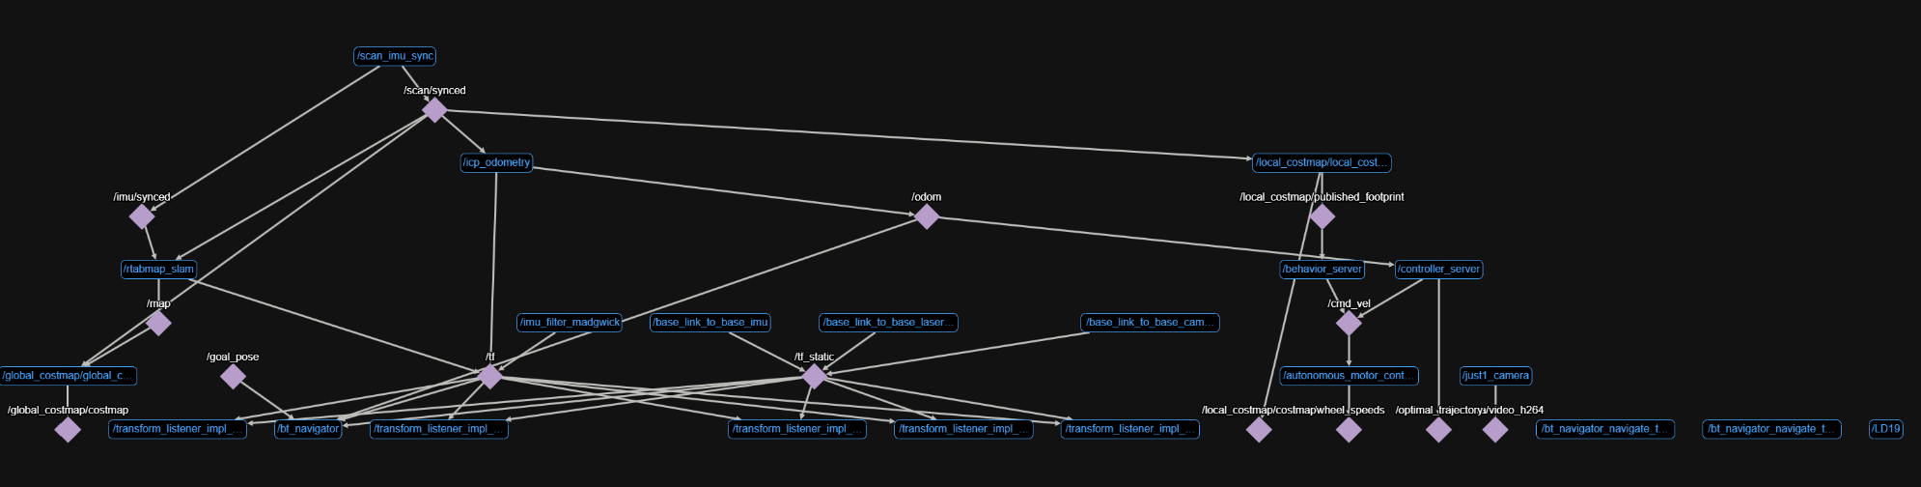
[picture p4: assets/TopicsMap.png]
TopicsMap


## Motor Control Nodes

### 1. Manual Motor Controller Node (`manual_controller_node.py`)
**Package:** `just1_motors`  
**Node Name:** `manual_controller_node`

**Role:** Controls the robot's motors using joystick input for manual operation.

**Functionality:**
- Subscribes to joystick data and converts it to wheel speed commands
- Implements dual-stick control system:
  - **Left Stick:** Controls forward/backward movement and turning (priority)
  - **Right Stick:** Controls spinning and lateral movement (when left stick is in deadzone)
- Applies deadzone (0.1) to prevent unwanted movement when controller is centered
- Calculates individual wheel speeds for mecanum drive system
- Directly controls motor hardware via GPIO

**Topics:**
- **Subscribes to:** `joy` (sensor_msgs/Joy) - **100Hz**
- **Publishes to:** `wheel_speeds` (just1_interface/WheelSpeeds) - **100Hz** (same as joystick input)

**Message Structure (WheelSpeeds):**
```yaml
float32 front_left    # Front left wheel speed (-100 to 100)
float32 front_right   # Front right wheel speed (-100 to 100)
float32 back_left     # Back left wheel speed (-100 to 100)
float32 back_right    # Back right wheel speed (-100 to 100)
```

---

### 2. Autonomous Motor Controller Node (`autonomous_controller_node.py`)
**Package:** `just1_motors`  
**Node Name:** `autonomous_motor_controller`

**Role:** Controls the robot's motors using autonomous navigation commands.

**Functionality:**
- Subscribes to velocity commands from navigation system
- Converts linear and angular velocities to wheel speeds using mecanum drive kinematics
- Converts wheel linear speeds to RPM internally, then to signed percent (-100 to 100) for both motor PWM and the `wheel_speeds` topic (same semantics as the manual controller)

**Topics:**
- **Subscribes to:** `cmd_vel` (geometry_msgs/Twist) - **Variable** (depends on navigation system)
- **Publishes to:** `wheel_speeds` (just1_interface/WheelSpeeds) - **Variable** (same as cmd_vel input); message fields are percent -100 to 100, not RPM

---

## Input Device Nodes

### 4. Joystick Driver Node (`joystick_node.py`)
**Package:** `just1_joystick_driver`  
**Node Name:** `joystick_driver`

**Role:** Interfaces with game controllers and joysticks to provide input data.

**Functionality:**
- Uses Pygame to detect and interface with connected controllers
- Supports multiple controller types (Nintendo Pro Controller, etc.)
- Reads all axes and buttons from the controller
- Publishes controller data at 100Hz (10ms intervals)
- Provides controller information logging (name, ID, connection status)

**Topics:**
- **Subscribes to:** None (direct hardware input)
- **Publishes to:** `joy` (sensor_msgs/Joy) - **100Hz**

**Message Structure (Joy):**
```yaml
std_msgs/Header header:
  time stamp
  string frame_id
float32[] axes        # Array of axis values (-1.0 to 1.0)
int32[] buttons       # Array of button states (0 or 1)
```

---

## Sensor Nodes

### 5. Camera Node (`camera_node.py`)
**Package:** `just1_camera`  
**Node Name:** `camera_node`

**Role:** Captures and publishes video feed from the Raspberry Pi camera.

**Functionality:**
- Uses Picamera2 library for optimized camera performance
- Captures frames at 640x480 resolution, 30 FPS
- Encodes video stream using H.264 compression
- Configures camera for low latency (disables noise reduction)
- Publishes compressed video data for efficient transmission

**Topics:**
- **Subscribes to:** None (direct camera input)
- **Publishes to:** `camera/video_h264` (foxglove_msgs/CompressedVideo) - **30Hz**

**Message Structure (CompressedVideo):**
```yaml
builtin_interfaces/Time timestamp
string format         # Compression format (e.g., "h264")
uint8[] data          # Compressed video data
```

---

### 6. IMU Node (`imu_node.py`)
**Package:** `just1_imu`  
**Node Name:** `mpu6050_publisher`

**Role:** Reads and publishes data from the MPU6050 IMU sensor.

**Functionality:**
- Interfaces with MPU6050 via I2C bus
- Provides configurable parameters:
  - I2C bus number
  - Publish rate (default: 10Hz)
  - Calibration samples (default: 100)
  - Gyroscope range (250-2000°/s)
  - Accelerometer range (2-16g)
- Performs automatic calibration on startup
- Applies deadzone filtering to reduce noise
- Converts raw sensor data to SI units (m/s², rad/s)

**Topics:**
- **Subscribes to:** None (direct I2C communication)
- **Publishes to:** `imu/data_raw` (sensor_msgs/Imu) - **10Hz** (configurable)

**Message Structure (Imu):**
```yaml
std_msgs/Header header:
  time stamp
  string frame_id
geometry_msgs/Quaternion orientation:
  float64 x, y, z, w
float64[9] orientation_covariance
geometry_msgs/Vector3 angular_velocity:
  float64 x, y, z    # Angular velocity in rad/s
float64[9] angular_velocity_covariance
geometry_msgs/Vector3 linear_acceleration:
  float64 x, y, z    # Linear acceleration in m/s²
float64[9] linear_acceleration_covariance
```

---

### 7. LiDAR Node

**Package:** `ldlidar_stl_ros2`  
**Node Name:** `LD19`  
**Source:** [`Constructor`](https://github.com/ldrobotSensorTeam/ldlidar_stl_ros2)

**Role:**  
Interfaces with LD19 (and LD06) LiDAR sensors to provide laser scan data to ROS 2.

**Functionality:**
- Supports LD06 and LD19 LiDAR models
- Configurable parameters:
  - Serial port and baudrate
  - Frame ID and topic name
  - Scan direction (clockwise/counterclockwise)
  - Angle cropping for specific field of view
- Converts raw LiDAR data to LaserScan messages
- Provides 360° coverage with configurable range (0.02-12m)
- Runs at 10Hz update rate
- **Captures 500 points per scan** (5000 Hz measurement frequency ÷ 10 Hz scan rate)
- **Angular resolution: 0.72°** between measurement points (360° ÷ 500 points)

**Topics:**
- **Subscribes to:** None (direct serial communication)
- **Publishes to:** `scan` (sensor_msgs/LaserScan) - **10Hz** (fixed by hardware)

**Message Structure (LaserScan):**
```yaml
std_msgs/Header header:
  time stamp
  string frame_id
float32 angle_min          # Start angle of scan (rad)
float32 angle_max          # End angle of scan (rad)
float32 angle_increment    # Angular distance between measurements (rad)
float32 time_increment     # Time between measurements (s)
float32 scan_time          # Time between scans (s)
float32 range_min          # Minimum range value (m)
float32 range_max          # Maximum range value (m)
float32[] ranges           # Range data (m)
float32[] intensities      # Intensity data
```

---

## Processing Nodes

### 8. IMU Filter Node (Madgwick)
**Package:** `imu_filter_madgwick`  
**Node Name:** `imu_filter_madgwick`

**Role:** Filters and fuses IMU data to provide orientation estimates.

**Functionality:**
- Applies Madgwick filter algorithm to raw IMU data
- Fuses accelerometer and gyroscope data
- Provides orientation quaternions
- Configurable gain and zeta parameters
- Optimized for real-time performance

**Topics:**
- **Subscribes to:** `imu/data_raw` (sensor_msgs/Imu) - **10Hz**
- **Publishes to:** `imu/data` (sensor_msgs/Imu) - **10Hz**

---

### 9. Scan-IMU Synchronization Node (`scan_imu_sync.py`)
**Package:** `just1_imu`  
**Node Name:** `scan_imu_sync`

**Role:** Synchronizes LiDAR scan data with IMU data for accurate odometry.

**Functionality:**
- Aligns timestamps between scan and IMU data
- Ensures temporal consistency for SLAM algorithms
- Provides synchronized data streams for navigation

**Topics:**
- **Subscribes to:** 
  - `/scan` (sensor_msgs/LaserScan) - **10Hz**
  - `/imu/data` (sensor_msgs/Imu) - **10Hz**
- **Publishes to:**
  - `/scan/synced` (sensor_msgs/LaserScan) - **10Hz**
  - `/imu/synced` (sensor_msgs/Imu) - **10Hz**

---

### 10. ICP Odometry Node
**Package:** `rtabmap_odom`  
**Node Name:** `icp_odometry`

**Role:** Computes robot odometry using Iterative Closest Point algorithm. Be able to locate the robot's position and orientation compared to its starting point.  
Allows to have the Transform tree between base_link and odom. 

**Functionality:**
- Uses LiDAR scan data and IMU for pose estimation. Could be improved with wheel encoders.
- Implements ICP algorithm for scan matching
- Provides 2D odometry estimates
- Configurable parameters for scan matching thresholds
- Publishes transform from odom to base_link frames

**Topics:**
- **Subscribes to:**
  - `/scan/synced` (sensor_msgs/LaserScan) - **10Hz**
  - `/imu/synced` (sensor_msgs/Imu) - **10Hz**
- **Publishes to:** `odom` (nav_msgs/Odometry) - **Should be 10Hz but around 8Hz with computation**

**Message Structure (Odometry):**
```yaml
std_msgs/Header header:
  time stamp
  string frame_id
string child_frame_id
geometry_msgs/PoseWithCovariance pose:
  geometry_msgs/Pose pose:
    geometry_msgs/Point position:
      float64 x, y, z
    geometry_msgs/Quaternion orientation:
      float64 x, y, z, w
  float64[36] covariance
geometry_msgs/TwistWithCovariance twist:
  geometry_msgs/Twist twist:
    geometry_msgs/Vector3 linear:
      float64 x, y, z
    geometry_msgs/Vector3 angular:
      float64 x, y, z
  float64[36] covariance
```
Covariance represent the uncertainty in the metrics. 

---

### 11. RTAB-Map SLAM Node
**Package:** `rtabmap_slam`  
**Node Name:** `rtabmap_slam`

**Role:** Performs Simultaneous Localization and Mapping (SLAM). Be able to locate the robot in a global map.  
Allows to have the Transform tree between odom and map. 

**Functionality:**
- Creates and maintains occupancy grid maps
- Performs loop closure detection
- Provides global localization
- Integrates scan and IMU data for accurate mapping
- Supports map saving and loading

**Topics:**
- **Subscribes to:**
  - `/scan/synced` (sensor_msgs/LaserScan) - **10Hz**
  - `/imu/synced` (sensor_msgs/Imu) - **10Hz**
- **Publishes to:** `map` (nav_msgs/OccupancyGrid) - **Variable** (updates when map changes)

**Message Structure (OccupancyGrid):**
```yaml
std_msgs/Header header:
  time stamp
  string frame_id
nav_msgs/MapMetaData info:
  time map_load_time
  float32 resolution      # Meters per pixel
  uint32 width           # Map width in pixels
  uint32 height          # Map height in pixels
  geometry_msgs/Pose origin:
    geometry_msgs/Point position:
      float64 x, y, z
    geometry_msgs/Quaternion orientation:
      float64 x, y, z, w
int8[] data              # Occupancy data (-1=unknown, 0=free, 100=occupied)
```

---

## Navigation Nodes (Nav2)

### Nav2 Architecture Overview

Nav2 (Navigation2) is a modular navigation framework that provides autonomous navigation capabilities for mobile robots.  
Great doc: https://docs.nav2.org/concepts/index.html

**Core Navigation Flow:**
1. **Goal Request** → Behavior Tree Navigator receives navigation goal
2. **Global Planning** → Planner Server computes path from current position to goal
3. **Local Control** → Controller Server follows path while avoiding obstacles
4. **Recovery** → Behavior Server handles stuck situations and failures

**Key Components and Relationships:**

- **Behavior Tree Navigator**: The main orchestrator that manages the entire navigation process using behavior trees. It coordinates between all other components and handles the navigation state machine.

- **Planner Server**: Computes global paths using the occupancy grid map. It finds collision-free (or at least minimal cost) routes from the robot's current position to the goal location.

- **Controller Server**: Converts global paths into velocity commands. It handles local path following, obstacle avoidance, and dynamic replanning when obstacles appear.

- **Behavior Server**: Provides recovery behaviors when the robot gets stuck or encounters navigation failures (e.g., spinning in place, backing up, waiting).

- **Lifecycle Manager**: Ensures all Nav2 components start and stop in the correct order, managing their lifecycle states.

**Behavior Tree Logic:**
The behavior tree manages navigation states and recovery:
- **NavigateToPose**: Main navigation behavior
- **ComputePathToPose**: Calls planner server for global path
- **FollowPath**: Calls controller server to follow the path
- **Recovery Behaviors**: Spin, backup, or wait when stuck
- **Condition Checks**: Monitor for goal completion, failures, or replanning needs

A few other components can be used: waypoint follower, speed limits etc.  

---

### 12. Lifecycle Manager
**Package:** `nav2_lifecycle_manager`  
**Node Name:** `lifecycle_manager_navigation`

**Role:** Manages the lifecycle of all Nav2 nodes.

**Functionality:**
- Starts and stops navigation nodes in correct order
- Handles node state transitions
- Ensures proper initialization sequence

---

### 13. Planner Server
**Package:** `nav2_planner`  
**Node Name:** `planner_server`

**Role:** Computes global paths from current position to goal.

**Functionality:**
- Uses occupancy grid map for path planning
- Implements various planning algorithms
- Provides collision-free paths
- Handles goal requests from navigation clients

**Topics:**
- **Subscribes to:** `map` (nav_msgs/OccupancyGrid) - **Variable**
- **Publishes to:** `global_plan` (nav_msgs/Path) - **On demand** (when path planning requested)

---

### 14. Controller Server
**Package:** `nav2_controller`  
**Node Name:** `controller_server`

**Role:** Converts global paths to velocity commands.

**Functionality:**
- Follows global path while avoiding obstacles
- Implements local path planning
- Provides velocity commands for motor control
- Handles dynamic obstacle avoidance

**Topics:**
- **Subscribes to:**
  - `scan` (sensor_msgs/LaserScan) - **10Hz**
  - `odom` (nav_msgs/Odometry) - **10Hz**
  - `global_plan` (nav_msgs/Path) - **On demand**
- **Publishes to:** `cmd_vel` (geometry_msgs/Twist) - **10Hz**

---

### 15. Behavior Tree Navigator
**Package:** `nav2_bt_navigator`  
**Node Name:** `bt_navigator`

**Role:** Orchestrates navigation behaviors using behavior trees.

**Functionality:**
- Manages navigation state machine
- Handles goal requests and cancellations
- Coordinates between planning and control
- Implements recovery behaviors

**Topics:**
- **Subscribes to:** Various navigation topics - **Variable**
- **Publishes to:** Navigation action goals and results - **On demand**

---

### 16. Behavior Server
**Package:** `nav2_behaviors`  
**Node Name:** `behavior_server`

**Role:** Implements specific navigation behaviors.

**Functionality:**
- Provides recovery behaviors (spin, backup, etc.)
- Handles stuck situations
- Implements safety behaviors

---

## Diagnostic Nodes

### 17. Diagnostics Node (`diagnostics_node.py`)
**Package:** `just1_diagnostics`  
**Node Name:** `diagnostics_node`

**Role:** Provides testing and diagnostic capabilities for the robot.

**Functionality:**
- Tests individual wheels and movements
- Validates joystick input
- Provides comprehensive movement testing:
  - Forward, backward, left, right
  - Diagonal movements
  - Spinning (clockwise/counterclockwise)
  - Curved movements
  - Complex patterns (square, lateral arc)
- Configurable test parameters and speeds

**Topics:**
- **Subscribes to:** `joy` (sensor_msgs/Joy) - **10Hz** (for joystick testing)
- **Publishes to:** None (direct motor control)

---

## Utility Nodes

### 18. Foxglove Bridge Node
**Package:** `foxglove_bridge`  
**Node Name:** `foxglove_bridge`

**Role:** Provides web-based visualization and monitoring interface.

**Functionality:**
- Bridges ROS2 topics to web interface
- Enables remote monitoring and control
- Provides real-time data visualization
- Runs on port 8765 by default

**Topics:**
- **Subscribes to:** All ROS2 topics (configurable) - **Variable**
- **Publishes to:** Web interface - **Variable** (bridges all subscribed topics)

---

### 19. Static Transform Publishers
**Package:** `tf2_ros`  
**Node Names:** `base_link_to_base_imu`, `base_link_to_base_laser_ld19`

**Role:** Define fixed spatial relationships between robot components.

**Functionality:**
- **IMU Transform:** 7cm forward, 180° rotation around Z-axis (base_link → imu_link)
- **LiDAR Transform:** 12cm up, 90° rotation around Z-axis (base_link → base_laser)
- Provides coordinate frame definitions for sensor fusion

## Operation Modes

The Just1 robot supports three main operation modes:

1. **Manual Mode:** Joystick control with camera feed
2. **Autonomous Mode:** Full navigation stack with SLAM
3. **Diagnostics Mode:** Testing and validation tools

Each mode activates different subsets of nodes based on the required functionality.

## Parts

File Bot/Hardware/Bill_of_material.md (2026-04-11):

# Bill of Material

These are the components used to build Just1. Prices are as of April 2026, for a US based purchase.

| Item | Qty | Description | Link (as of April 2026) | Total Price (as of April 2026) | Why |
| --- | --- | --- | --- | --- | --- |
| Control Unit | 1 | Raspberry Pi 5 8GB | [Link](https://www.lemona.lt/mini-kompiuteris-raspberry-pi-5-su-16gb-ram.html) | 200€ | Pi 5 brings a significantly faster CPU and better PCIe/IO over Pi 4. 8GB headroom is useful for running on-device ML inference alongside ROS. |
| Micro SD card | 1 | 32GB Micro SD Card (A2 rated) | [Link](https://www.lemona.lt/atminties-kortele-microsd-32gb-class-10-uhs-i-u1-su-sd-adapteriu.html) | 12€ | A2-rated card gives noticeably faster random I/O on Pi 5 boot and file access. |
| Encoder Motors | 4 | DFRobot TT Geared Motor with Encoder — FIT0450 (I-shape, 6V 160RPM 120:1) | [Link](https://pl.farnell.com/en-PL/dfrobot/fit0450/dc-geared-motor-brushed-120-1/dp/3769977) | 26€ (~6,36€ each) | TT form-factor DC geared motor with built-in quadrature hall effect encoder (ENC_A + ENC_B). Copper D-shaped output shaft fits standard 60mm mecanum wheel hubs. 160 RPM at 6V. A hardware 6V motor buck steps the LiPo voltage down, meaning we can safely run at a full 100% PWM 0-255 scale in software. Running current: ~0.17A no-load, ~0.5A loaded. Stall current: 2.8A — above TB6612FNG 1.2A continuous rating, but below its 3.2A peak; avoid sustained stall (encoder-fed stall watchdog and latch in `utils_motors.py` / `encoder_watcher.py`). |
| Mecanum Wheels | 1 | 60mm Mecanum Wheel Set for TT Motor (2× left + 2× right, includes wheel hub adapters) | [Link](https://www.aliexpress.com/item/1005002905313817.html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) | 10€ | Rubber-coated 60mm mecanum wheels with TT D-shaft hub adapters included. 2 left-hand + 2 right-hand wheels required for correct holonomic drive (strafe, rotate-in-place, diagonal). |
| Frame | 1 | Frame | [Link](https://www.aliexpress.com/item/1005011860055142.html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) | 10€ |  |
| Motor Drivers | 2 | TB6612FNG Dual Motor Driver | [Link](https://www.aliexpress.com/item/1005005130932194.html) | 4€ | MOSFET-based dual H-bridge, 1.2A/channel continuous (3.2A peak). Replaces L298N: no voltage drop waste, operates directly from Pi 3.3V GPIO. 15V max motor supply — safely fed 6.0V by our dedicated motor buck converter. 2 modules × 2 channels each = 4 motors total. |
| Motor current sense (optional) | 1–4 | INA219 or INA226 breakout (I2C), shunt on VM return or per-channel high-side sense | (vendor of choice) | — | Backup to encoder-based stall detection: software or comparator trip can cut PWM/STBY if motor current exceeds a safe threshold (e.g. sustained above 1.2A per TB6612FNG continuous rating). Useful if an encoder cable fails and `feed_watchdog()` stops updating. |
| AI Camera | 1 | Raspberry Pi AI Camera (Sony IMX500) | [Link](https://www.anodas.lt/en/raspberry-pi-ai-camera-12mpx-original-raspberry-pi-camera-with-imx500-intelligent-vision-sensor) | 86€ | On-sensor neural network inference via the IMX500 — object detection runs on the camera chip itself, offloading the Pi. |
| Pan/Tilt stack | 1 | 2× SG90-class micro servo + PCA9685 16-channel PWM driver (mount/mechanism as needed) | [Link](https://www.amazon.com/dp/B07VPH4X6Q) | 16€ | PCA9685 on ESP32 I2C (not a Pi HAT); servo V+ from the XL4016 5V rail per power architecture. |
| Lidar | 1 | LD19 Lidar | [Link](https://www.aliexpress.com/item/1005008606058253.html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) | 70€ | Relatively cheap 2D Lidar for navigation and obstacle avoidance. |
| IMU | 1 | MPU6050 IMU | [Link](https://www.aliexpress.com/item/1005008604349573.html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) | 3€ | 6-axis gyro+accelerometer for orientation feedback. |
| Wake Controller | 1 | ESP32 DevKit C (38-pin) | [Link](https://www.aliexpress.com/item/1005007173771226.html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) | 10€ | Handles smart wake-up (Pi has no Wake-on-LAN). Stays in deep-sleep (μA draw), wakes on BLE/button/timer, then triggers the high-side switch to power the Pi. |
| Pi 5V Switch | 1 | 1-Channel 5V Relay Module with Optocoupler (High-Level Trigger) | [Link](https://www.aliexpress.com/item/1005006579751839.html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) | 2€ | ESP32 GPIO 32 triggers the relay to open/close the 5V rail to the Pi. This ready-to-use module has screw terminals (no soldering needed). It isolates the circuit and acts as a high-side switch to safely preserve the shared system ground. Ensure to power the relay board with 5V, but it can trigger from the 3.3V GPIO. |
| Pi Power | 1 | DC-DC Buck Converter 5V/8A (40W) — XL4016 | [Link](https://www.aliexpress.com/item/1005008128479310.html) | 4€ | Steps down the 4S LiPo battery voltage (up to 16.8V) to a stable 5V/8A rail. Pi 5 can draw up to 5A under load; pan/tilt SG90s draw stall current via PCA9685 V+ on this same 5V rail (up to ~700mA each) — a 40W budget is required. Do not substitute with LM2596(HV) which is rated 3A and will overheat under load. |
| Main Battery | 1 | 4S Graphene LiPo Battery (1300mAh, 14.8V, 75C) | Supplied by user | 0€ | Extremely lightweight drone battery. Dramatically reduces robot weight (~150g vs 800g), greatly improving TT motor performance and strafing capability. |
| Motor Buck Converter | 1 | DC-DC Buck Converter 6V/8A (40W) — XL4016 | [Link](https://www.aliexpress.com/item/1005008128479310.html) | 4€ | Steps down the 16.8V battery max voltage to exactly 6.0V for the motor driver `VM` pins. Protects the TB6612FNG (15V limit) and provides enough headroom (8A) to handle simultaneous stalls of multiple TT motors (2.8A peak each) without voltage collapse or overheating. Do not use an LM2596 as it will overheat during motor stalls. |
| Low Voltage Alarm | 1 | BX100 RC LiPo Voltage Alarm | (vendor of choice) | 2€ | Plugs into the LiPo balance port. Sounds an extremely loud buzzer when any cell drops to a safe threshold to prevent permanent battery damage or fire. |
| **Total** | | | | **459€~** | |

<br>
<br>

Here are a bunch of useful screws and wires.
| Item | Qty | Link (as of April 2026) | Total Price (as of April 2026) | Why |
| --- | --- | --- | --- | --- |
| Female Female Jumper Wires | 1 | [Link](https://www.amazon.com/dp/B09FP5PW45) | $7 | Connect Pi to Motor Drivers, ESP32, and sensors. |
| Various 2.5 Screws | 1 | [Link](https://www.amazon.com/dp/B0CRRCYZHS) | $10 | Screw Pi, Motor Drivers, ESP32 to chassis. |
| Hex Pylons | 1 | [Link](https://www.amazon.com/dp/B01EYQ1TGE) | $10 | Separate both layers of 3D model. |
| On/Off Switch | 1 | [Link](https://www.amazon.com/dp/B0C53HD8J7) | $6 | Hard power cut for the whole battery rail when storing the robot. |
| XT60 Connector + 18AWG wire | 1 | [Link](https://www.amazon.com/TMH-Upgrade-Female-Connectors-Battery/dp/B0F53RRR94) | $8 | Robust connection between the 4S LiPo pack and the power distribution point. |
| 74LVC125A Quad Level Shifter | 2 | [Link](https://www.amazon.com/dp/B07VNQX59J) | $6 (5-pack) | Shifts encoder signal lines from 5V (motor encoder VCC) down to 3.3V (Pi 5 GPIO safe input). Each chip has 4 channels; 2 chips cover all 8 encoder signals (ENC_A + ENC_B × 4 motors). The LVC variant is specifically designed to accept 5V input while powered from 3.3V — do not use AHCT or HC variants, which do not support overvoltage on input when VCC is 3.3V. |
| Flexible CSI Camera Ribbon Cable — 20cm | 1 | [Link](https://www.amazon.com/dp/B07SX8NWRT) | $6 | The standard short CSI ribbon would fatigue and break under repeated pan/tilt movement. A 20cm flexible extension provides enough slack for ±90° pan and ±45° tilt without stressing the connector. Route the cable along the tilt axis rotation point. |

You'll also need standard wires, soldering iron, and a standard RC LiPo balance charger. Do NOT plug the LiPo directly into a wall adapter, and DO NOT use a LiFePO4 charging profile — it must be set to standard LiPo (4.2V/cell).

---

See `Architecture/` for full power and system architecture diagrams.

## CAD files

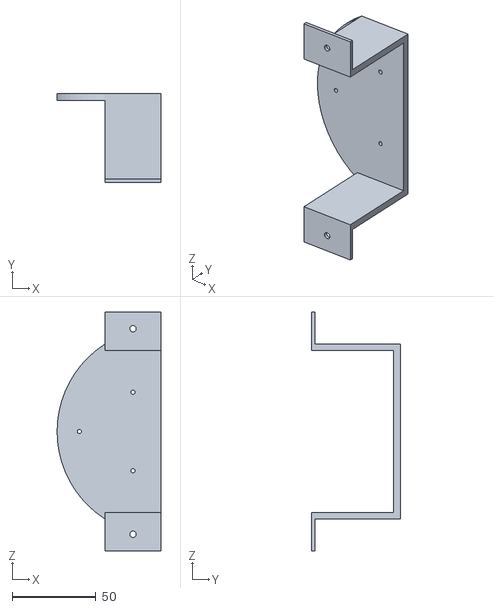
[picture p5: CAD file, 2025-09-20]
Bot/Hardware/CAD/ToPrint/LD19 Holder.STL
61.9 x 53.0 x 142.5

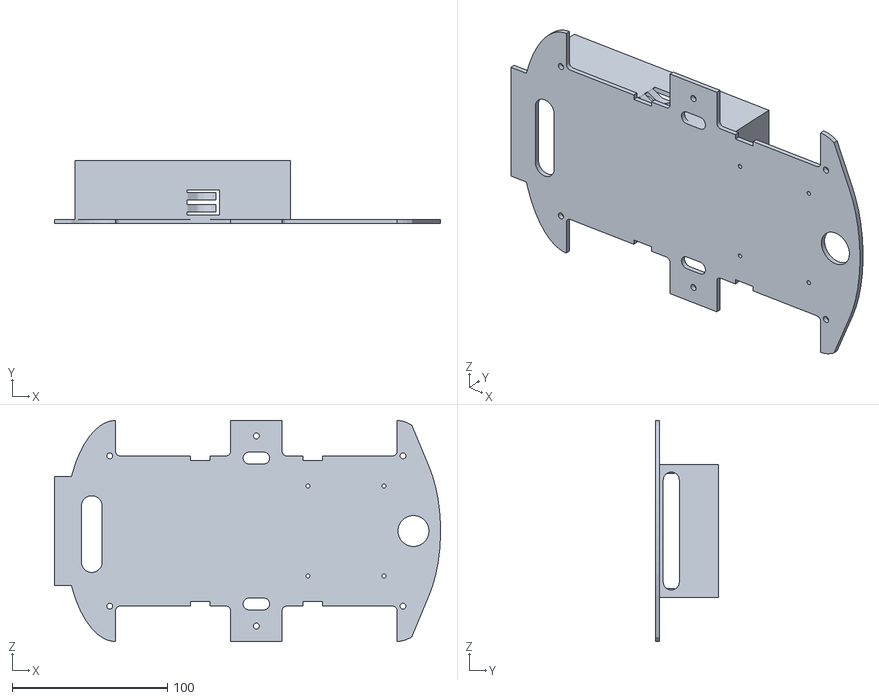
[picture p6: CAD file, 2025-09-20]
Bot/Hardware/CAD/ToPrint/Car chassis - top.STL
248.8 x 40.8 x 142.5

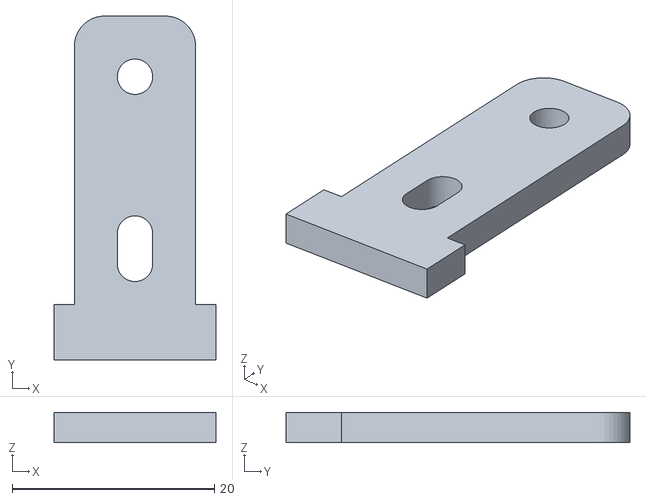
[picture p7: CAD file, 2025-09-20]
Bot/Hardware/CAD/ToPrint/Holder Motor.STL
16.0 x 34.0 x 3.00

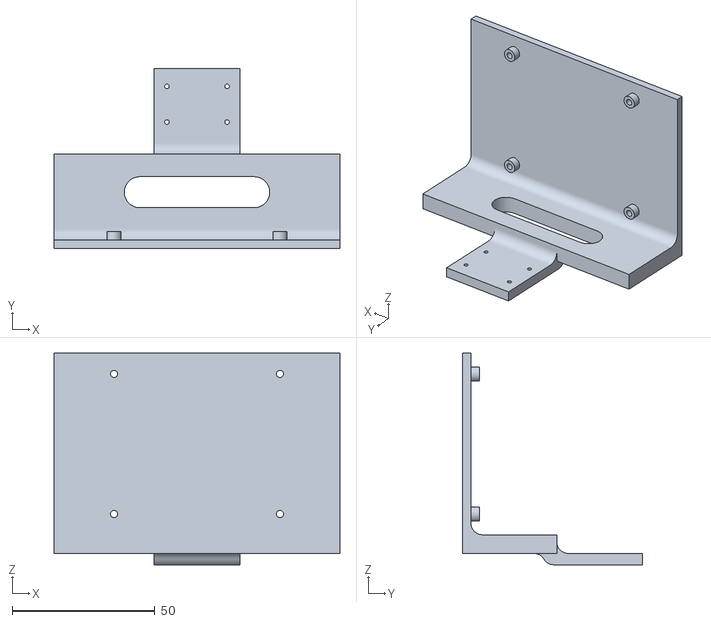
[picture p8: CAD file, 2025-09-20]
Bot/Hardware/CAD/ToPrint/Raspberry Holder.STL
100.0 x 63.0 x 74.0

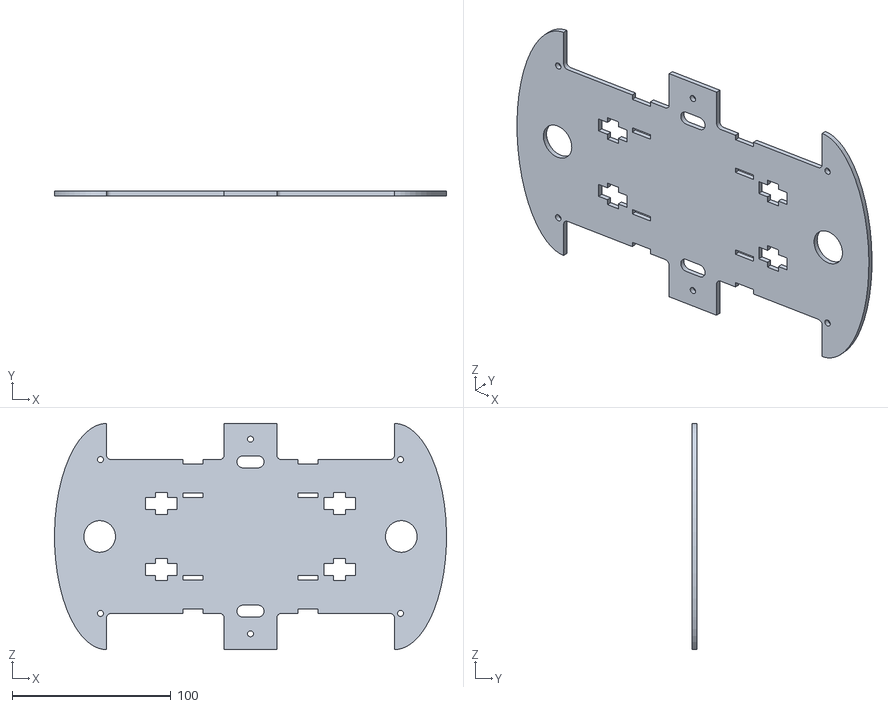
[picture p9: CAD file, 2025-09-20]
Bot/Hardware/CAD/ToPrint/Car chassis bottom.STL
247.0 x 2.85 x 142.5

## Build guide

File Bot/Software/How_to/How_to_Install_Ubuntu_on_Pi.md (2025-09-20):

# Install Ubuntu on Raspberry Pi 
## Step 1: Download Ubuntu Image

1. Go to the [Ubuntu Raspberry Pi page](https://ubuntu.com/raspberry-pi).
2. Download your preferred version (e.g., Ubuntu Server 24.04 LTS). Make sure to install Ubuntu Server instead of Ubuntu Desktop if you want to avoid plugging keyboard and mouse on the Pi.

---

## Step 2: Flash the Image to microSD

1. Download and install the [Raspberry Pi Imager](https://www.raspberrypi.com/software/).
2. Launch the Imager and:
   - **Choose OS**: Select “Other general-purpose OS > Ubuntu”
   - **Choose Storage**: Select your microSD card
   - **Customize before writing**:
     - You should have a popup offering you to input custom settings
     - Enable **Set hostname** (e.g., `raspberrypi.local`). This will allow to connect to it without IP address
     - Enable and set **SSH** (e.g., username `your-username`, password `your-password`)
     - Enable and configure **Wi-Fi**:
       - SSID: `your-network-name`
       - Password: `your-password`
       - Wi-Fi country: `US` (or your 2-letter country code)

3. Click **Save**, then **Write** to flash the image.

---

## Step 3: First Boot

1. Insert the microSD into your Raspberry Pi.
2. Power it on.

The Pi will:
- Automatically connect to the Wi-Fi
- Enable SSH access
- Be ready for headless setup

Wait for 5-10 min for the installation to complete

---

## Step 4: Connect via SSH

Once the Pi is online, open a terminal on your computer and connect using:

```bash
ssh your-username@raspberrypi
```

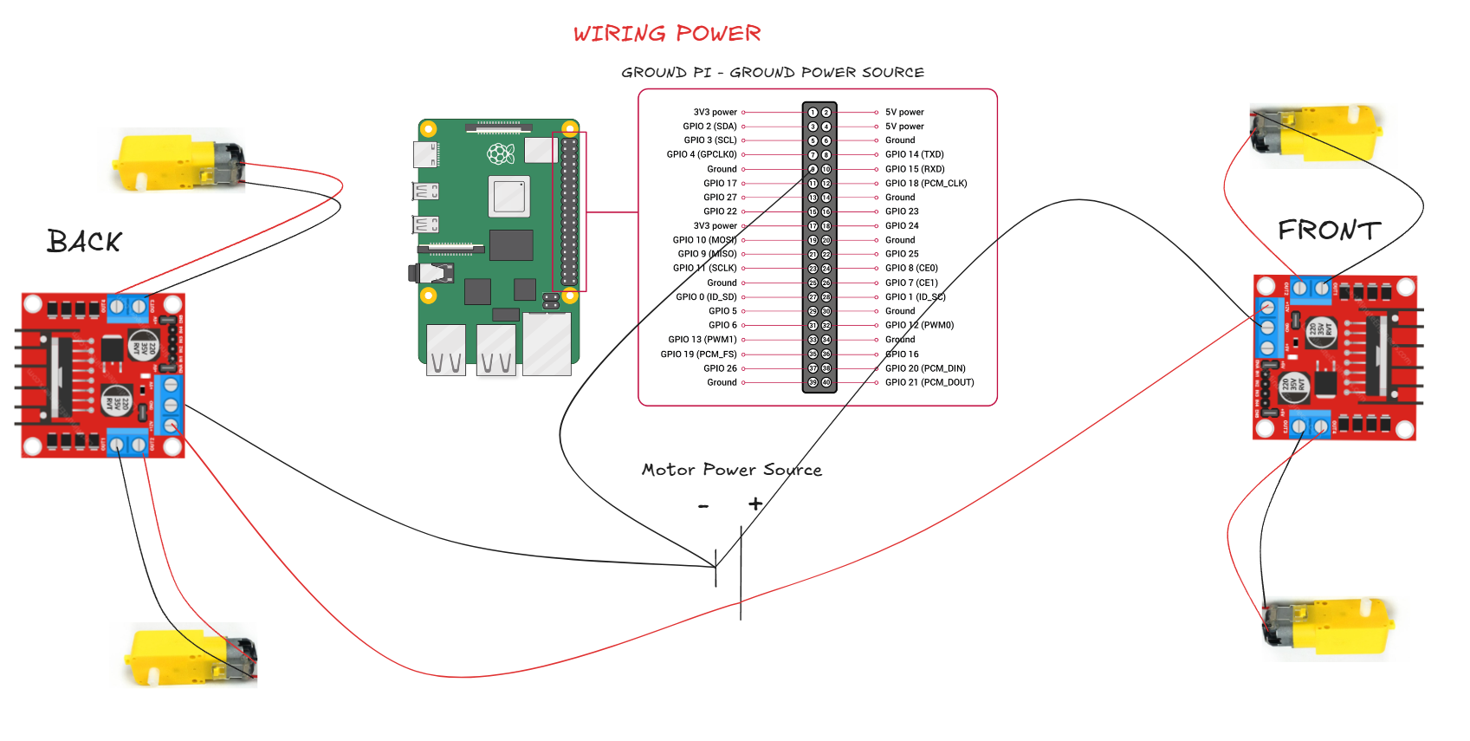
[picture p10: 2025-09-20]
Bot/Hardware/WiringPower.png

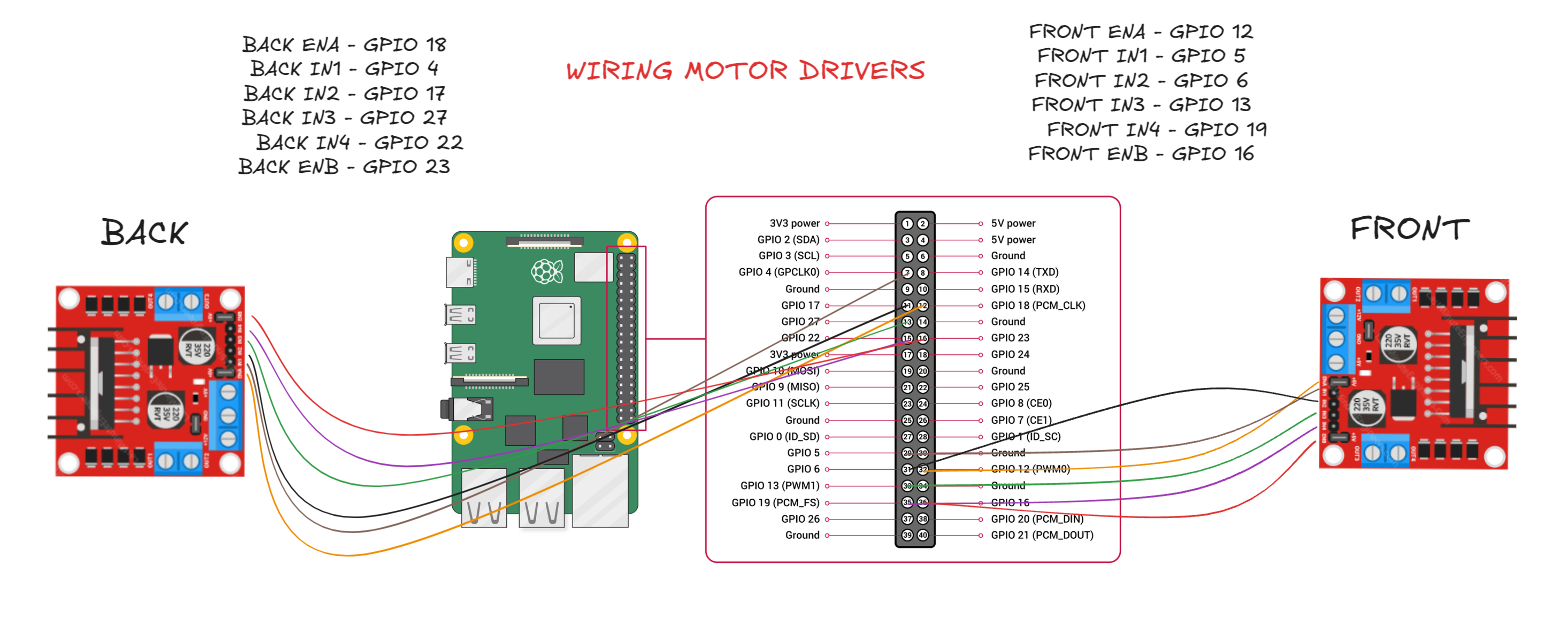
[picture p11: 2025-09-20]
Bot/Hardware/WiringMotorDrivers.png

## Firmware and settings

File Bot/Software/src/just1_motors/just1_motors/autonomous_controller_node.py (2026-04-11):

import rclpy
from rclpy.node import Node
from geometry_msgs.msg import Twist
from just1_interface.msg import WheelSpeeds
from just1_motors.utils_motors import setup, stop_all, control_wheel, cleanup
import math
import time


class AutonomousMotorController(Node):
    """
    Listens to the /cmd_vel topic and publishes the wheel speeds to the wheel_speeds topic.
    Controls a mecanum drive robot with 4 wheels.
    """

    def __init__(self):
        super().__init__("autonomous_motor_controller")

        # Initialize motor hardware
        setup()

        # Robot parameters for mecanum drive
        self.wheel_radius = 0.03  # meters (30mm radius)
        self.wheel_separation_x = (
            0.11  # meters (distance between front and back wheels)
        )
        self.wheel_separation_y = (
            0.13  # meters (distance between left and right wheels)
        )
        # The FIT0450 motor is rated 160 RPM at 6V. The drone battery voltage is safely
        # stepped down to exactly 6V by a dedicated hardware buck converter before 
        # reaching the motor driver. Because 100% PWM duty cycle now equals exactly 6V, 
        # the motor achieves exactly its nameplate 160 RPM at max speed.
        # This gives perfectly accurate 1:1 mapping for Nav2 velocity commands.
        self.max_rpm = 160

        # Create subscriber for cmd_vel
        self.cmd_vel_subscription = self.create_subscription(
            Twist, "cmd_vel", self.cmd_vel_callback, 10
        )

        # Create publisher for wheel speeds
        self.wheel_speeds_publisher = self.create_publisher(
            WheelSpeeds, "wheel_speeds", 10
        )

        # Watchdog: timestamp of the last received cmd_vel message.
        # If no message arrives within CMD_VEL_TIMEOUT_SEC, stop_all() is called.
        # This prevents the robot from running indefinitely if Nav2 crashes or
        # the final zero-velocity message is dropped over the network.
        self._CMD_VEL_TIMEOUT_SEC = 0.5
        self._last_cmd_vel_time = self.get_clock().now()
        self._watchdog_timer = self.create_timer(
            0.1, self._watchdog_callback  # runs at 10 Hz
        )

        self.get_logger().info("Autonomous Motor Controller initialized")

    def cmd_vel_callback(self, msg):
        """
        Callback function for cmd_vel messages.
        Converts linear and angular velocities to wheel speeds for mecanum drive.
        """
        # Reset watchdog timestamp on every received message.
        self._last_cmd_vel_time = self.get_clock().now()

        # Extract velocities
        linear_x = msg.linear.x
        linear_y = msg.linear.y
        angular_z = msg.angular.z

        # Calculate wheel speeds for mecanum drive (in RPM)
        wheel_speeds = self.calculate_mecanum_wheel_speeds(
            linear_x, linear_y, angular_z
        )

        # Convert wheel speeds to percent based on max RPM
        wheel_speeds_percent = self.rpm_to_percent(wheel_speeds)

        wheel_speeds_msg = WheelSpeeds()
        wheel_speeds_msg.front_left = float(wheel_speeds_percent["front_left"])
        wheel_speeds_msg.front_right = float(wheel_speeds_percent["front_right"])
        wheel_speeds_msg.back_left = float(wheel_speeds_percent["back_left"])
        wheel_speeds_msg.back_right = float(wheel_speeds_percent["back_right"])

        self.wheel_speeds_publisher.publish(wheel_speeds_msg)

        self.control_motors(wheel_speeds_percent)

    def _watchdog_callback(self):
        """
        Called at 10 Hz. Stops all motors if no /cmd_vel has been received
        within CMD_VEL_TIMEOUT_SEC. Prevents indefinite motor runaway when
        Nav2 crashes, the goal is reached without a final zero-velocity message,
        or the operator disconnects.
        """
        elapsed = (
            self.get_clock().now() - self._last_cmd_vel_time
        ).nanoseconds / 1e9
        if elapsed > self._CMD_VEL_TIMEOUT_SEC:
            stop_all()

    def calculate_mecanum_wheel_speeds(self, linear_x, linear_y, angular_z):
        """
        Calculate wheel speeds for mecanum drive based on desired velocities.

        Args:
            linear_x: Forward/backward velocity (m/s)
            linear_y: Left/right velocity (m/s)
            angular_z: Rotational velocity (rad/s)

        Returns:
            dict: Wheel speeds for each wheel with the speed in RPM
        """
        # Mecanum wheel speed equations
        # Front left: vx - vy - (Lx + Ly) * ω
        # Front right: vx + vy + (Lx + Ly) * ω
        # Back left: vx + vy - (Lx + Ly) * ω
        # Back right: vx - vy + (Lx + Ly) * ω

        Lx = self.wheel_separation_x / 2.0
        Ly = self.wheel_separation_y / 2.0

        front_left = linear_x - linear_y - (Lx + Ly) * angular_z
        front_right = linear_x + linear_y + (Lx + Ly) * angular_z
        back_left = linear_x + linear_y - (Lx + Ly) * angular_z
        back_right = linear_x - linear_y + (Lx + Ly) * angular_z

        # Convert from m/s to RPM (approximate)
        # RPM = (m/s) / (2 * π * radius) * 60
        rpm_factor = 60.0 / (2.0 * math.pi * self.wheel_radius)

        wheel_speeds = {
            "front_left": front_left * rpm_factor,
            "front_right": front_right * rpm_factor,
            "back_left": back_left * rpm_factor,
            "back_right": back_right * rpm_factor,
        }

        return wheel_speeds

    def rpm_to_percent(self, wheel_speeds):
        """
        Convert wheel speeds from RPM to percent based on max RPM.
        Args:
            wheel_speeds: dict containing speeds for each wheel (in RPM)
        Returns:
            dict: Wheel speeds as percentages (-100.0 to 100.0)
        """
        percent_speeds = {}
        for wheel_name, rpm in wheel_speeds.items():
            percentage = (rpm / self.max_rpm) * 100.0
            percentage = max(-100.0, min(100.0, percentage))
            percent_speeds[wheel_name] = percentage
        return percent_speeds

    def control_motors(self, wheel_speeds):
        """
        Control motors based on calculated wheel speeds.

        Args:
            wheel_speeds: dict containing speeds for each wheel (in percent)
        """
        for wheel_name, percentage in wheel_speeds.items():
            control_wheel(wheel_name, int(round(percentage)))

    def on_shutdown(self):
        """
        Cleanup when node is shutting down.
        """
        self.get_logger().info("Shutting down Autonomous Motor Controller")
        stop_all()
        cleanup()


def main(args=None):
    rclpy.init(args=args)

    autonomous_controller = AutonomousMotorController()

    try:
        rclpy.spin(autonomous_controller)
    except KeyboardInterrupt:
        pass
    finally:
        autonomous_controller.on_shutdown()
        autonomous_controller.destroy_node()


if __name__ == "__main__":
    main()

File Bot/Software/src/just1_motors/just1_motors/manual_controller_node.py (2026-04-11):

import rclpy
from rclpy.node import Node
from sensor_msgs.msg import Joy
from just1_interface.msg import WheelSpeeds
from just1_motors.utils_motors import setup, stop_all, control_wheel, cleanup


class ManualMotorController(Node):
    """
    This node is used to control the robot using a joystick.
    It subscribes to the joystick topic and publishes the wheel speeds to the wheel_speeds topic.
    The left stick is used to control the robot and make it move forward, backward, and turn left and right.
    The right stick is used to control the robot and make it spin clockwise and counterclockwise, or move laterally left or right.
    The left stick has priority over the right stick. The left stick must be in deadzone for right stick to be used.
    A deadzone of 0.1 is applied to the joystick to prevent the robot from moving when the controller is in the center.
    """

    def __init__(self):
        super().__init__("manual_controller_node")

        # Initialize GPIO and motors
        setup()

        # Create subscriber for joystick input
        self.subscription = self.create_subscription(Joy, "joy", self.joy_callback, 10)

        # Create publisher for wheel speeds. Published at the same speed as the Joystick message
        self.publisher = self.create_publisher(WheelSpeeds, "wheel_speeds", 10)

        self.get_logger().info("Manual Motor Controller initialized")

    def joy_callback(self, msg):
        # Get joystick values from the left stick
        vertical_value_left = msg.axes[1]  # Left stick vertical
        horizontal_value_left = msg.axes[0]  # Left stick horizontal

        vertical_value_right = msg.axes[3]  # Right stick vertical
        horizontal_value_right = msg.axes[2]  # Right stick horizontal

        # Check if left stick is out of deadzone and if so, calculate wheel speeds
        if abs(vertical_value_left) > 0.1 or abs(horizontal_value_left) > 0.1:
            wheel_speeds = self.calculate_wheel_speeds_left_stick(
                vertical_value_left, horizontal_value_left
            )
        # Else, use right stick values to control the robot
        else:
            wheel_speeds = self.calculate_wheel_speeds_right_stick(
                vertical_value_right, horizontal_value_right
            )

        # Apply speeds to wheels
        for wheel, speed in wheel_speeds.items():
            control_wheel(wheel, speed)

        # Publish wheel speeds
        speeds_msg = WheelSpeeds()
        speeds_msg.front_left = float(wheel_speeds["front_left"])
        speeds_msg.front_right = float(wheel_speeds["front_right"])
        speeds_msg.back_left = float(wheel_speeds["back_left"])
        speeds_msg.back_right = float(wheel_speeds["back_right"])
        self.publisher.publish(speeds_msg)

    @staticmethod
    def _reduce_magnitude(value, amount):
        """Reduce |value| by amount, clamping at zero (never flips sign)."""
        if value > 0:
            return max(0.0, value - amount)
        elif value < 0:
            return min(0.0, value + amount)
        return 0.0

    def calculate_wheel_speeds_left_stick(self, vertical_value, horizontal_value):
        """
        Calculate the speed for each wheel based on vertical and horizontal values of the left joystick.
        Values range from -1 to 1, where:
        - vertical: -1 is full forward, 1 is full backward
        - horizontal: -1 is full left, 1 is full right

        Returns a dictionary with speeds for each wheel (-100 to 100)

        It first assigns base speed depending on the vertical value. Then it adds horizontal speed to the right wheels depending on the horizontal value in order to turn left or right.
        """
        # Initialize speeds
        speeds = {"front_left": 0, "front_right": 0, "back_left": 0, "back_right": 0}

        # Apply deadzone so that the robot doesn't move when the controller is in the center
        if abs(vertical_value) <= 0.1 and abs(horizontal_value) <= 0.1:
            return speeds

        # Calculate base speed (0 to 100)
        vertical_speed = abs(vertical_value) * 100
        horizontal_speed = abs(horizontal_value) * 100

        # Handle vertical movement
        if vertical_value < -0.1:  # Forward
            speeds = {wheel: vertical_speed for wheel in speeds.keys()}
        elif vertical_value > 0.1:  # Backward
            speeds = {wheel: -vertical_speed for wheel in speeds.keys()}

        # Handle horizontal movement
        if horizontal_value < -0.1:  # Turn left
            # Right wheels get additional speed
            speeds["front_right"] += horizontal_speed
            speeds["back_right"] += horizontal_speed
            # Left wheels get reduced speed (sign-aware so reverse turning works)
            speeds["front_left"] = self._reduce_magnitude(speeds["front_left"], horizontal_speed)
            speeds["back_left"] = self._reduce_magnitude(speeds["back_left"], horizontal_speed)
        elif horizontal_value > 0.1:  # Turn right
            # Left wheels get additional speed
            speeds["front_left"] += horizontal_speed
            speeds["back_left"] += horizontal_speed
            # Right wheels get reduced speed (sign-aware so reverse turning works)
            speeds["front_right"] = self._reduce_magnitude(speeds["front_right"], horizontal_speed)
            speeds["back_right"] = self._reduce_magnitude(speeds["back_right"], horizontal_speed)

        # Ensure speeds are within -100 to 100 range
        for wheel in speeds:
            speeds[wheel] = max(-100, min(100, speeds[wheel]))

        return speeds

    def calculate_wheel_speeds_right_stick(self, vertical_value, horizontal_value):
        """
        Calculate the speed for each wheel based on vertical and horizontal values of the right joystick.
        Values range from -1 to 1, where:
        - vertical: -1 is spin clockwise, 1 is spin counterclockwise
        - horizontal: -1 is move laterally left, 1 is move laterally right

        The movement cannot be at the same time horizontal and vertical. The highest speed will be used.
        """
        speeds = {"front_left": 0, "front_right": 0, "back_left": 0, "back_right": 0}

        # Apply deadzone so that the robot doesn't move when the controller is in the center
        if abs(vertical_value) <= 0.1 and abs(horizontal_value) <= 0.1:
            return speeds

        # Calculate base speed (0 to 100)
        vertical_speed = abs(vertical_value) * 100
        horizontal_speed = abs(horizontal_value) * 100
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

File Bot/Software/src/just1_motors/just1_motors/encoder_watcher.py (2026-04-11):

from gpiozero import DigitalInputDevice

_ENC_A_PINS = (
    (4, "front_left"),
    (6, "front_right"),
    (16, "back_left"),
    (21, "back_right"),
)

_devices = []


def start(feed_fn):
    global _devices
    stop()
    for pin, wheel_name in _ENC_A_PINS:

        def tick(wn=wheel_name):
            feed_fn(wn)

        d = DigitalInputDevice(
            pin,
            pull_up=False,
            bounce_time=None,
        )
        d.when_activated = tick
        d.when_deactivated = tick
        _devices.append(d)


def stop():
    global _devices
    for d in _devices:
        try:
            d.close()
        except Exception:
            pass
    _devices = []

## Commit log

2025-09-20 Initial Commit Public
    [Car chassis - top.STL, Car chassis bottom.STL, Holder Motor.STL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]
2026-04-07 minor update on materials
2026-04-11 minor fixes, different battery
    [autonomous_controller_node.py, utils_motors.py]
